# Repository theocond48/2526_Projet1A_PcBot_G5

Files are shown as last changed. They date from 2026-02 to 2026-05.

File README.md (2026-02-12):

# 2526_Projet1A_PcBot_G5

**Objectif :** Concevoir un robot communicant (Swarm) pour la cartographie d'environnement.
**Volume horaire :** 40 heures (10 séances x 4h).

- Travail en groupe réalisé par: Youssef Chemrakhi, Théodore Condette, Rayan Taoussi, Samy, Maroua Qidi.

# I - Phase 1 : Conception et Saisie de Schéma
- **Séance 1 : Initialisation & Spécifications**

- **Définition du Besoin**
  - Liste des fonctionnalités
  - Schéma architectural
- **Planification et Matériel**
  - Planning prévisionnel
  - Choix des composants

# 1 - Liste des fonctionnalités
Le robot doit être capable de:
- **Navigation et Évitement d'obstacles :** Détection d'objets en temps réel via les capteurs **VL53L0X (TOF)** pour ajuster la trajectoire.
- **Localisation Relative:** Suivi du déplacement et de l'orientation grâce à la centrale inertielle **LSM6DSOX** (Accéléromètre/Gyroscope).
- **Cartographie Collaborative :** Envoi des points de données de l'environnement vers les autres robots ou une station de base via le module **nRF24**.
- **Gestion de Swarm :** Capacité à recevoir des instructions ou à partager sa position pour éviter que deux robots ne couvrent la même zone.
- **Pilotage de Puissance :** Contrôle précis de la vitesse et de la direction des micro-moteurs **DFR1224** via le driver **DRV8411A**.
- **Autonomie Énergétique :** Recharge sécurisée de la batterie Li-ion et monitoring de la tension via le contrôleur **BQ25896**.

## 1.2 -Détails des composants 

## BMS bq25896

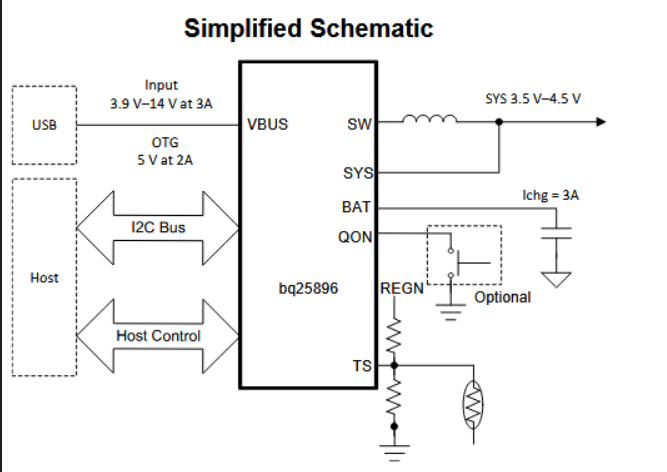
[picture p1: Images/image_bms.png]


- **C'est quoi ?** Le gestionnaire d'énergie intelligent.
    
- **Sa mission :**
    
    1. Il prend le 5V de l'USB pour charger la batterie LiPo en toute sécurité.
        
    2. Il protège la batterie (surcharge/décharge profonde).
        
    3. Il fournit l'énergie principale (SYS) au reste du robot.
        
- **Pourquoi c'est vital ?** Sans lui, ta batterie LiPo pourrait prendre feu ou mourir prématurément.

### Pin configuration BMS :

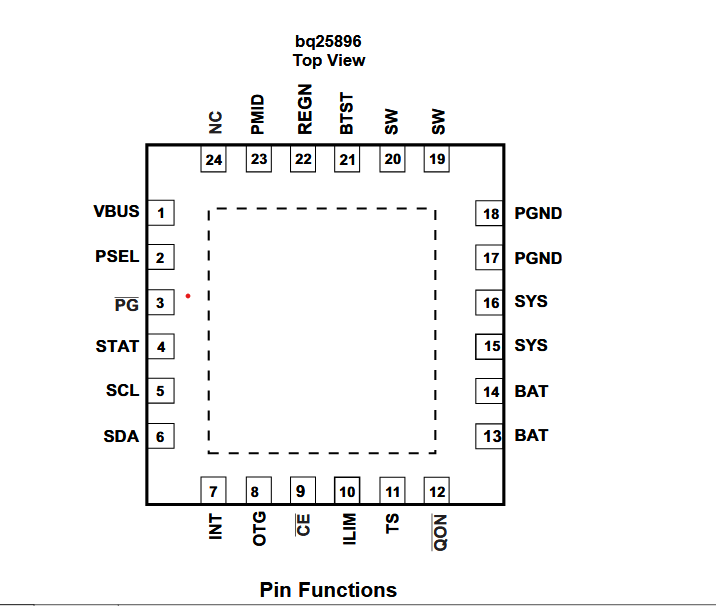
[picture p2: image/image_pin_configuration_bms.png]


**Netlist:**

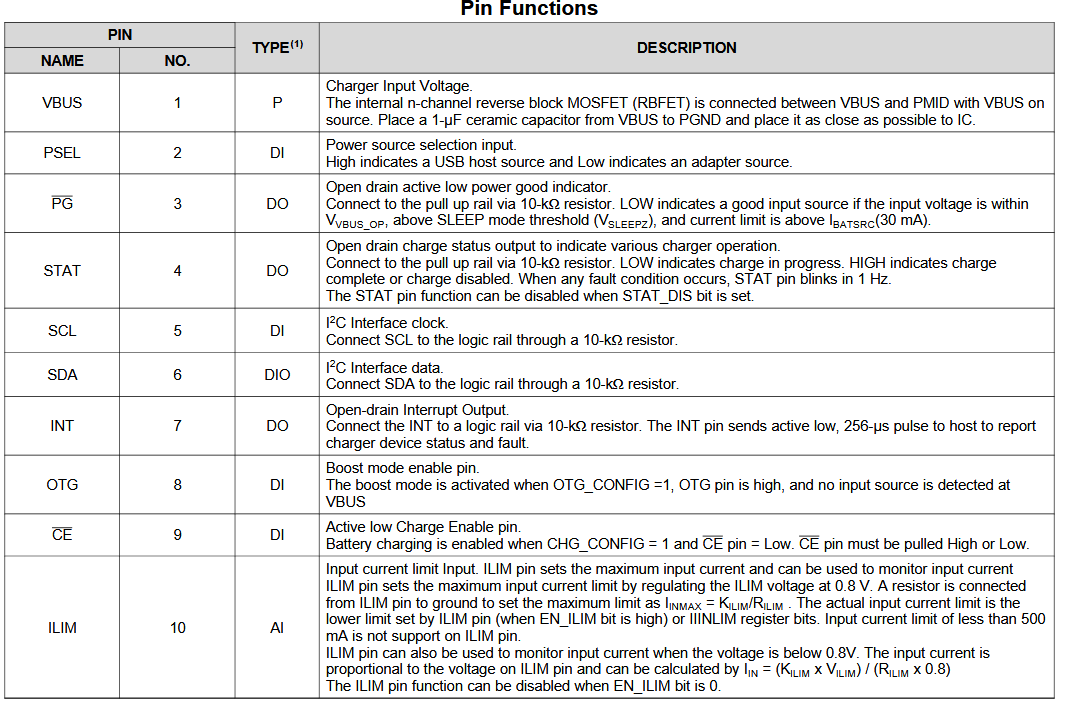
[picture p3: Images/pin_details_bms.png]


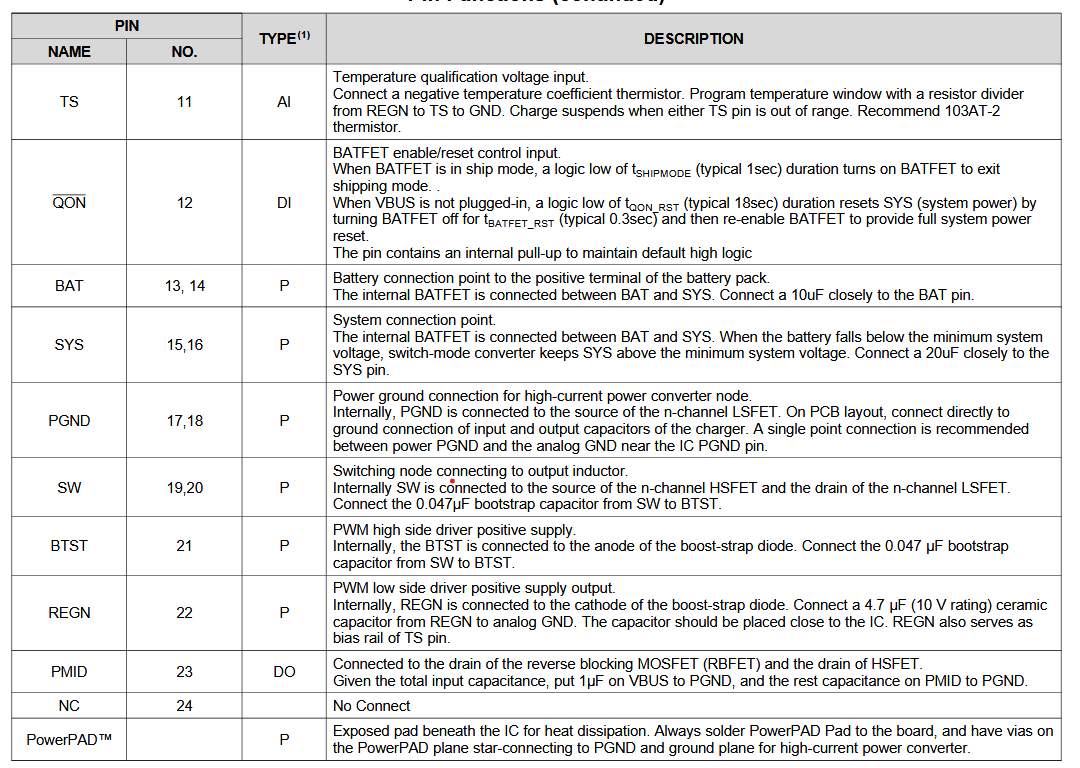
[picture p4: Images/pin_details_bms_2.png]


## Motor's Driver DRV8411A 

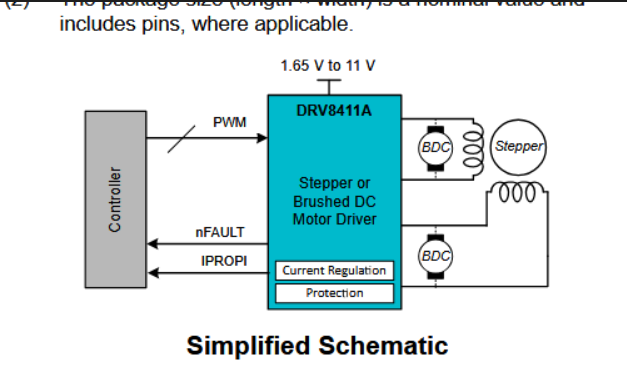
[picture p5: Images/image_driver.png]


- **C'est quoi ?** L'amplificateur de puissance.
    
- **Sa mission :** Le STM32 est trop faible pour faire tourner les moteurs directement. Le DRV8411A prend les petits ordres logiques (3.3V) et ouvre les vannes du "gros courant" venant de la batterie pour faire tourner les roues.
    
- **Pourquoi c'est vital ?** Il protège le STM32 des retours de courant inductif des moteurs.
### Pin configuration Driver

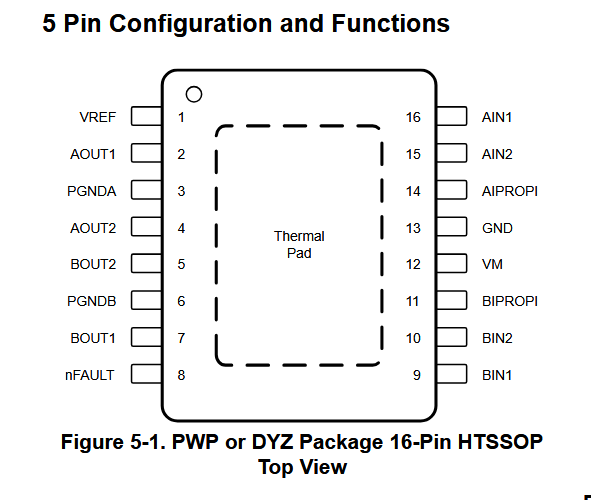
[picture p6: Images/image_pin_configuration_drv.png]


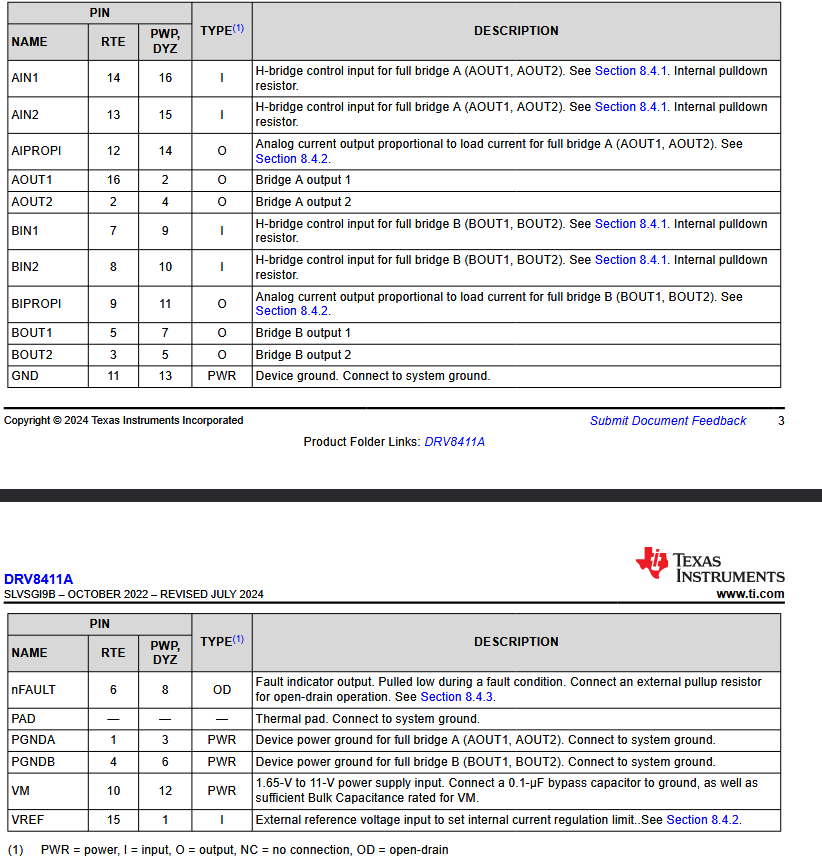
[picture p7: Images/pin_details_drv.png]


## imu adafruit (centrale inertielle)

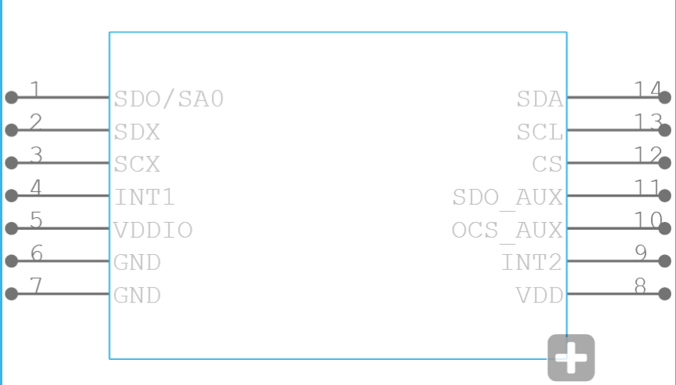
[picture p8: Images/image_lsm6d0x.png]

 LSM6DSOX (IMU - Accéléromètre/Gyroscope)

- **C'est quoi ?** Le capteur d'équilibre et de mouvement.
    
- **Sa mission :** Il sent si le robot accélère, tourne, ou s'il cogne un mur (choc). Il permet de faire avancer le robot bien droit (en corrigeant la trajectoire si une roue tourne plus vite que l'autre).
    
### Pin configuration imu

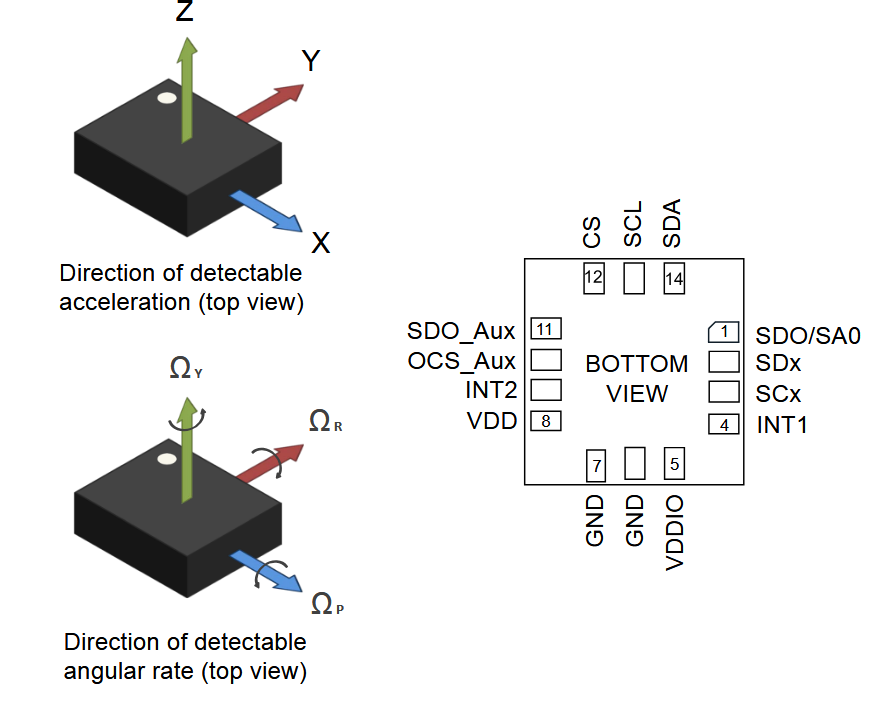
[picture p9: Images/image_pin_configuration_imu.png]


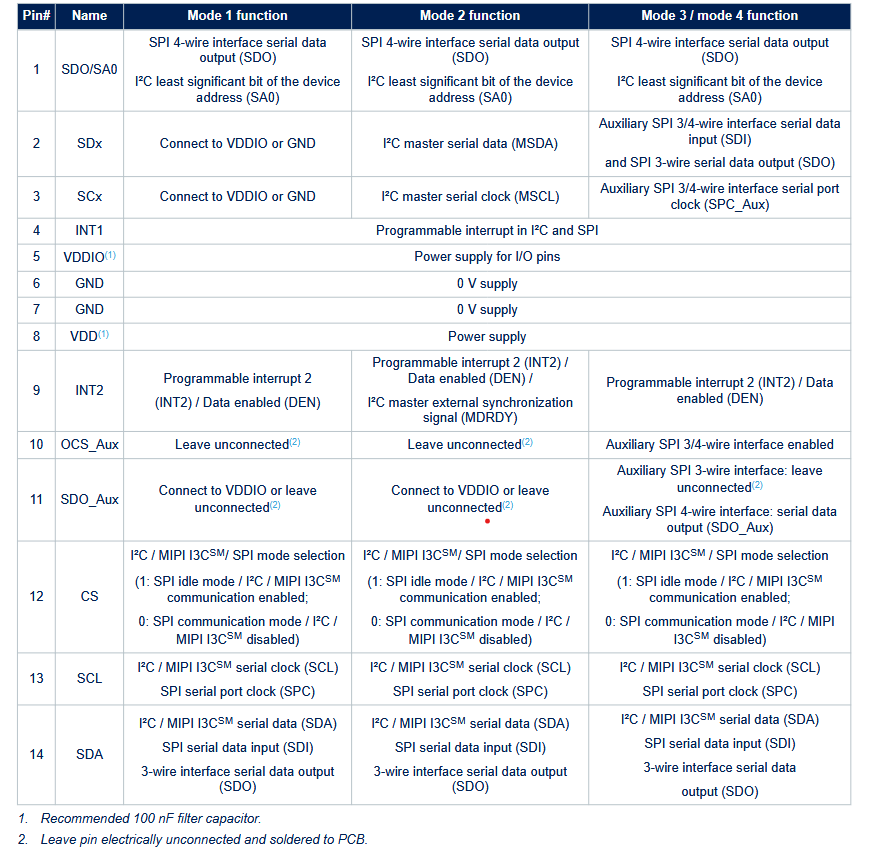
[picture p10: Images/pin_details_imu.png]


## Tof vl53lx
VL53L0X (ToF - Time of Flight)

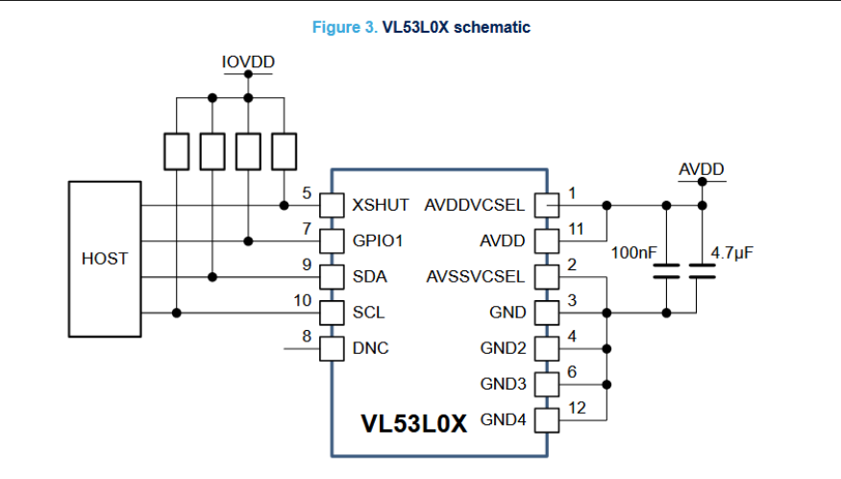
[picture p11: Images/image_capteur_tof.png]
image capteur


- **C'est quoi ?** Le télémètre laser.
    
- **Sa mission :** Il envoie un rayon de lumière invisible (infrarouge) et mesure le temps qu'il met à revenir. Cela lui donne la distance précise de l'obstacle devant lui (en millimètres).

### Pin configuration tof
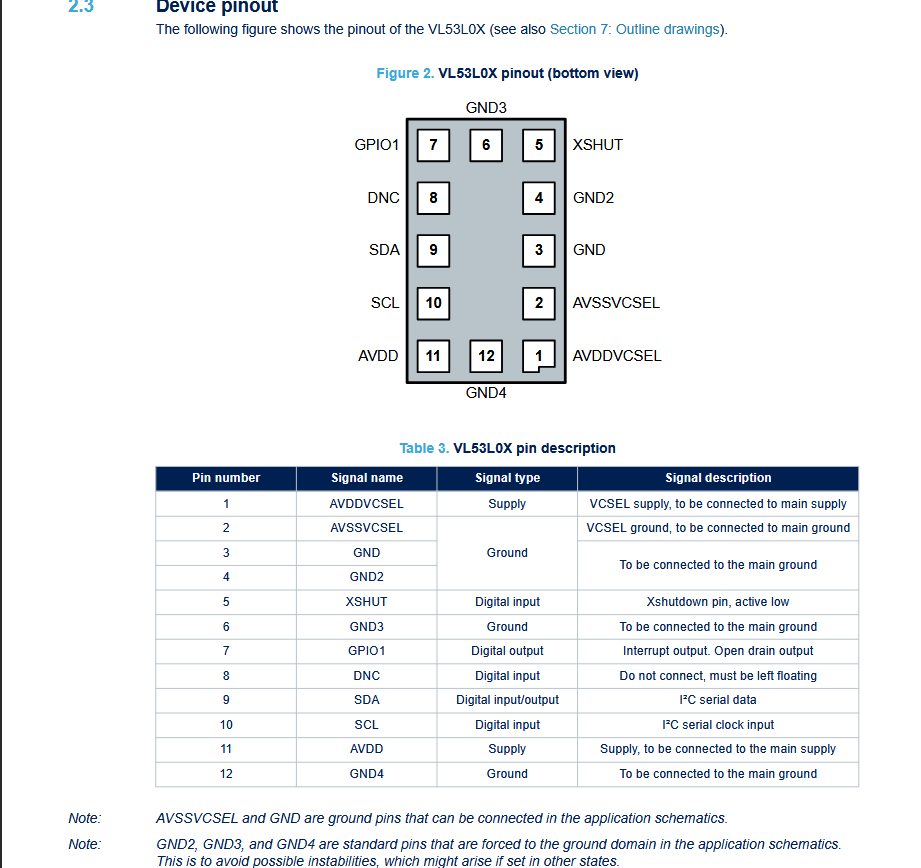
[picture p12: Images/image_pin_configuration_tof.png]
pin capteur

VL53L0X (ToF - Time of Flight)

- **C'est quoi ?** Le télémètre laser.
    
- **Sa mission :** Il envoie un rayon de lumière invisible (infrarouge) et mesure le temps qu'il met à revenir. Cela lui donne la distance précise de l'obstacle devant lui (en millimètres).

## motor DFR1224
(Moteurs N20 3V)

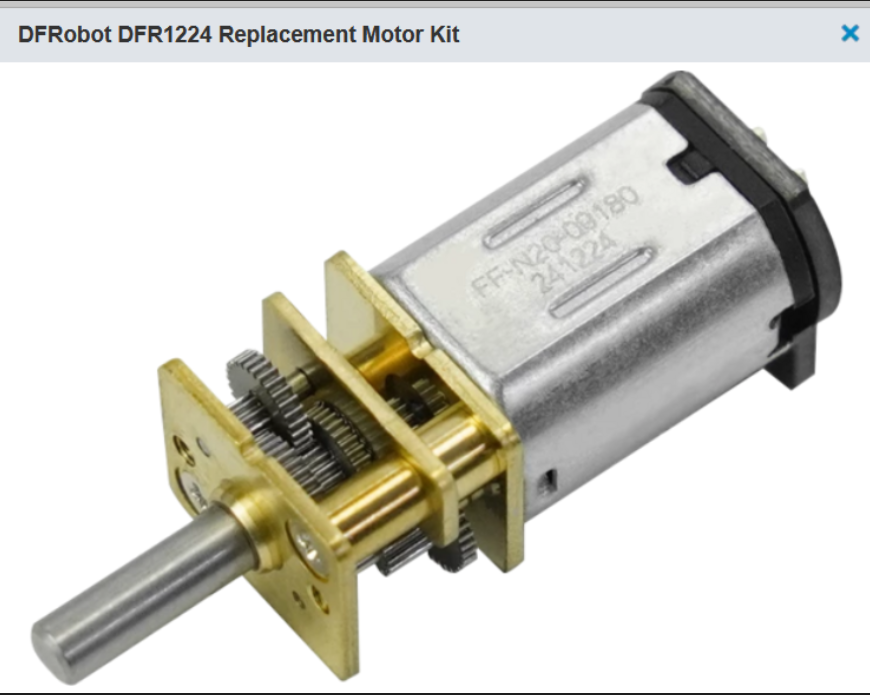
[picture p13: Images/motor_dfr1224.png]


- **C'est quoi ?** Les actionneurs.
    
- **Sa mission :** Convertir l'électricité en mouvement mécanique. Ils ont une boîte de vitesses (engrenages) intégrée pour avoir du couple (force) plutôt que de la vitesse pure.
    
- **Rappel critique :** Ce sont des moteurs **3V**. Ils doivent être alimentés avec précaution via le PWM du driver.

## module de communication nRF24l01
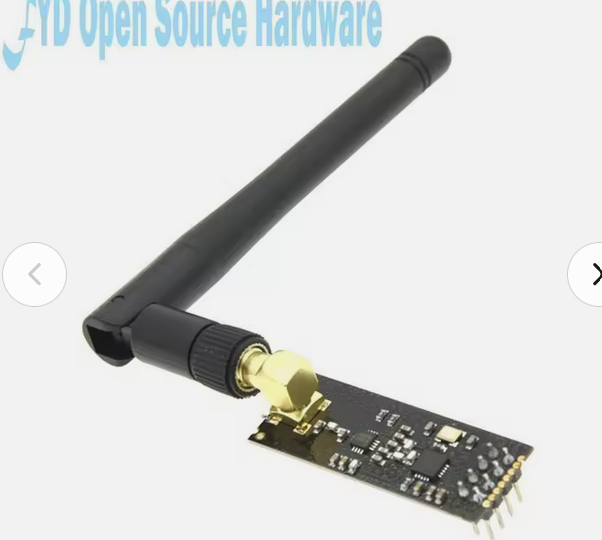
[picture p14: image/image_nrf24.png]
image nrf


### Pin configuration nrf
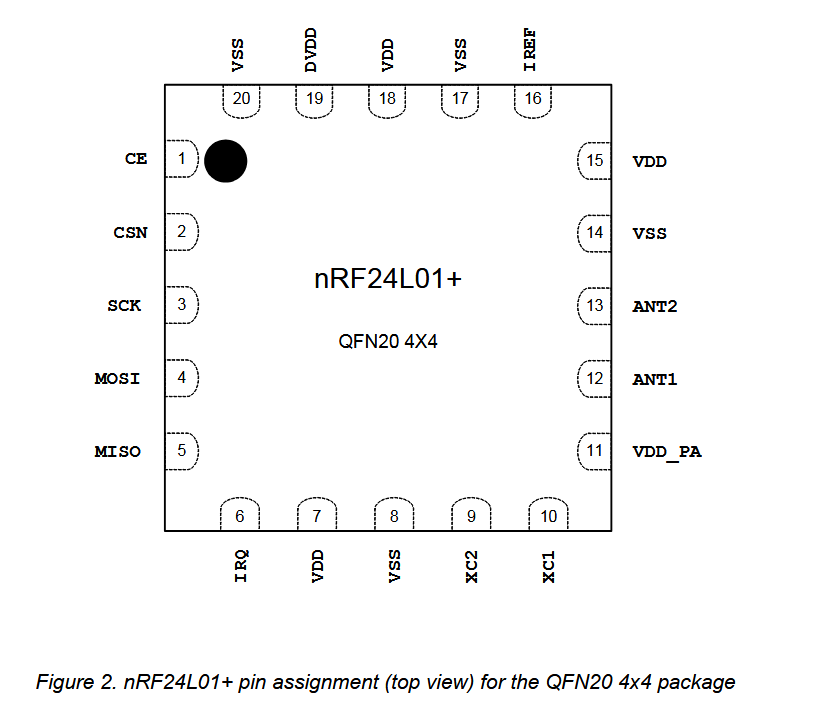
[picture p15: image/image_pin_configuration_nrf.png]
pin nrf


**Netlist**
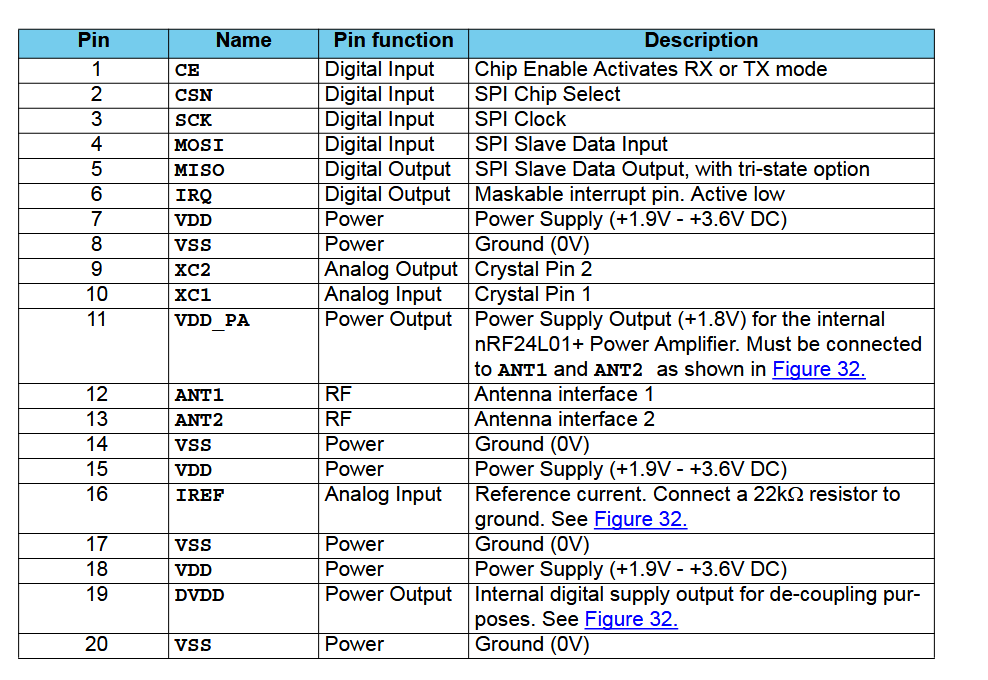
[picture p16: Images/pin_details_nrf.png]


# 2 - Schéma architectural

Le schéma ci-dessous illustre l'organisation du système. Le microcontrôleur (MCU) agit comme le cerveau central, coordonnant les capteurs (entrées), les actionneurs (sorties) et la communication.

```mermaid
graph TD
    %% Alimentation
    subgraph Power_System [Gestion Énergie]
        BAT[Batterie Li-ion] --- BMS[BMS: BQ25896]
        BMS -- I2C --> MCU[STM32L476]
    end

    %% Capteurs
    subgraph Perception [Capteurs / Entrées]
        TOF[Télémètres: VL53L0X] -- I2C --> MCU
        IMU[Centrale Inertielle: LSM6DSOX] -- I2C --> MCU
    end

    %% Communication
    subgraph Comms [Lien Essaim]
        nRF[Radio: nRF24L01] <-->|SPI| MCU
    end

    %% Actionneurs
    subgraph Motion [Actionneurs / Sorties]
        MCU -- PWM --> DRV[Driver: DRV8411]
        DRV --> M1[Moteur Gauche: DFR1224]
        DRV --> M2[Moteur Droit: DFR1224]
    end

    %% Styles
    style MCU fill:#f9f,stroke:#333,stroke-width:2px
    style BMS fill:#dfd
    style nRF fill:#ddf
```

Afin d'assurer les connexions données, on se reposera sur la Datasheet qui nous donne l'ensembles des ports de la STM32L476 qui sont configurés en I2C et SPI:

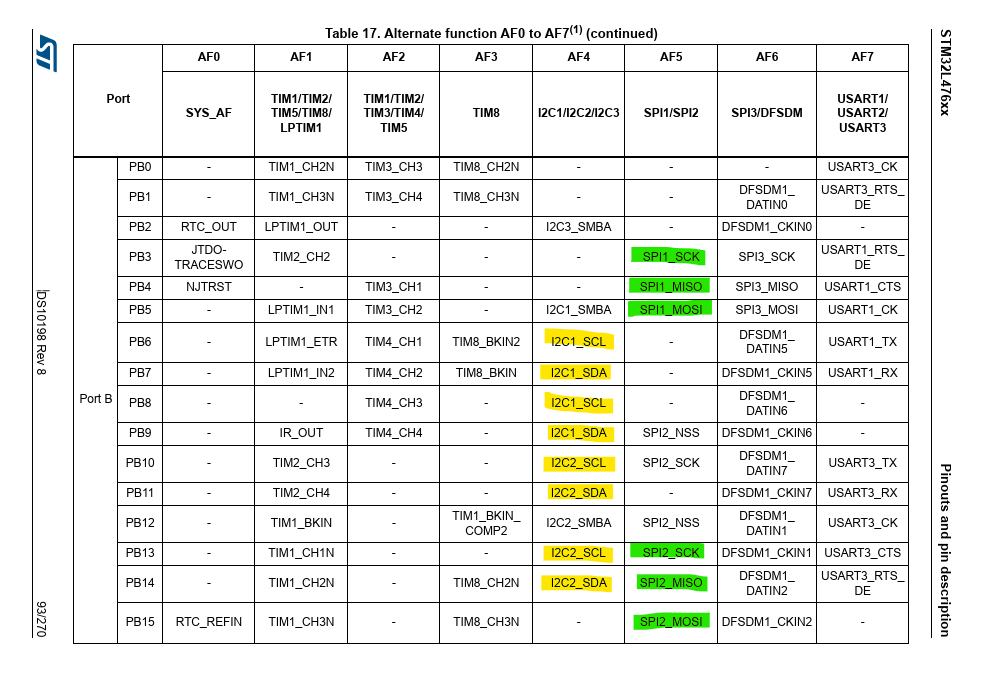
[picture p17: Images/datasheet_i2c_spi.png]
Tableau des fonctions alternées STM32


# 3 - Planning Prévisionnel - Projet PCBot

## Phase 1 : Conception et Saisie de Schéma
- **Séance 1 : Initialisation & Spécifications**
  - Formation du groupe.
  - Création du dépôt Git et ajout du professeur (laurent.fiack@ensea.fr).
  - Étude des composants : Capteurs TOF, Accéléromètre, nRF24, Batterie/Chargeur.
- **Séance 2 : Saisie de schéma**
  - Début de la saisie sur KiCad des blocs d'alimentation et du microcontrôleur.
- **Séance 3 : Revue de schéma & Finalisation**
  - Revue critique des connexions.
  - Finalisation du schéma complet avant les vacances de février.

## Phase 2 : Routage et Fabrication
- **Séance 4 : Placement et Routage**
  - Placement des composants sur le PCB.
  - Routage des pistes.
- **Séance 5 : Revue de routage & Commande**
  - **Critique :** Validation finale du routage.
  - Génération et envoi des fichiers de fabrication (Gerber).

## Phase 3 : Firmware et Intégration
- **Séance 6 : Tests préliminaires & Firmware**
  - Tests sur cartes de développement.
  - Développement des drivers pour les capteurs TOF et le module nRF24.
- **Séance 7 : Développement Firmware**
  - Implémentation des algorithmes de cartographie et de communication Swarm.
- **Séance 8 : Firmware & Soudure**
  - Réception possible des PCB.
  - Assemblage (soudure) et tests de continuité.
- **Séance 9 : Intégration Finale & Débogage**
  - Tests en conditions réelles du robot.
  - Correction des derniers bugs du firmware.

## Phase 4 : Clôture
- **Séance 10 : Finitions & Démo**
  - 2h : Préparation finale et finitions.
  - 2h : Présentation et démonstration du projet.

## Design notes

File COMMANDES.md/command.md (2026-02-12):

## Rappels Git

### Clé SSH

Créer une clé :

```bash
ssh-keygen
```

Afficher la clé ssh

```bash
cat /c/Users/<USER>/.ssh/id_ed25519.pub
```

### Cloner un projet

Clonage = récupérer le projet. A faire une fois par projet. 

```bash
cd <chemin/vers/le/bon/dossier>
git clone git@github.com:theocond48/2526_Projet1A_PcBot_G5.git
```

### Voir l'état du projet

```bash
git status
```

### Pousser des modifications 

On dit "committer" ou "faire un commit".
A faire à chaque fois qu'on a une nouvelle version fonctionnelle.

```bash
git add .   # Ajoute tous les fichiers
git commit -m "Message"
git push    # Pousse les modifications
```

### Récupérer les dernières mises à jour

A faire à chaque fois qu'on commence à travailler.

```bash
git pull
```

### Créer un fichier sur git ou un dossier

```bash
# Sur Mac ou Linux (ou terminal Git Bash) Pour un fichier :
touch nom.md

# Pour un dossier
mkdir nom
```

### Changer de branche

```bash
git checkout nom-de-la-branche
```

### Créer une branche

```bash
# -b, c'est pour créer la branche puis s'y déplacer directement.
git checkout -b nom-de-la-nouvelle-branche
```

### Comment faire un merge sur Github

C'est pour travailler proprement en équipe, éviter d'écraser le travail des autres et garder un historique clair.

```bash
# On se place sur la branche qui doit recevoir les changements :
git checkout base-branch

# On met à jour cette branche :
git pull

# On merge la branche de travail :
git merge compare-branch

# Si tout va bien, on pushe :
git push
```

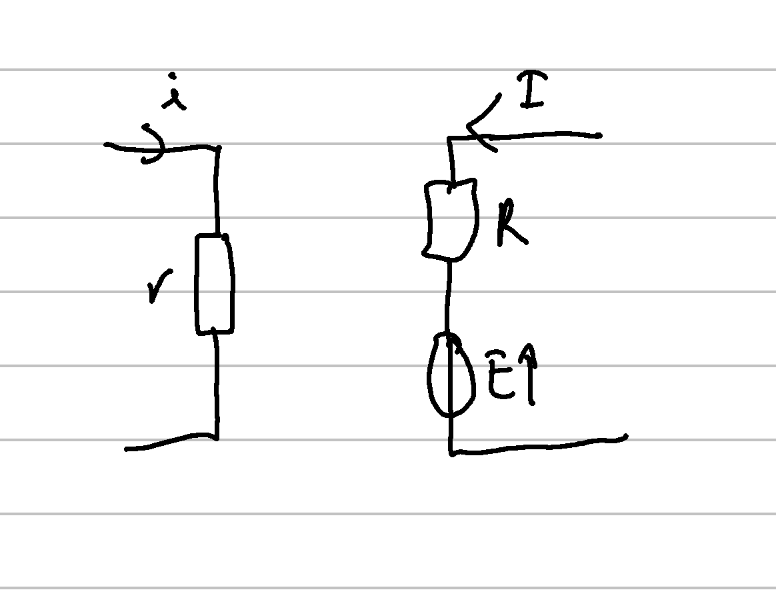
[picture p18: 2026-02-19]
image/Capture d’écran 2026-02-18 081915.png

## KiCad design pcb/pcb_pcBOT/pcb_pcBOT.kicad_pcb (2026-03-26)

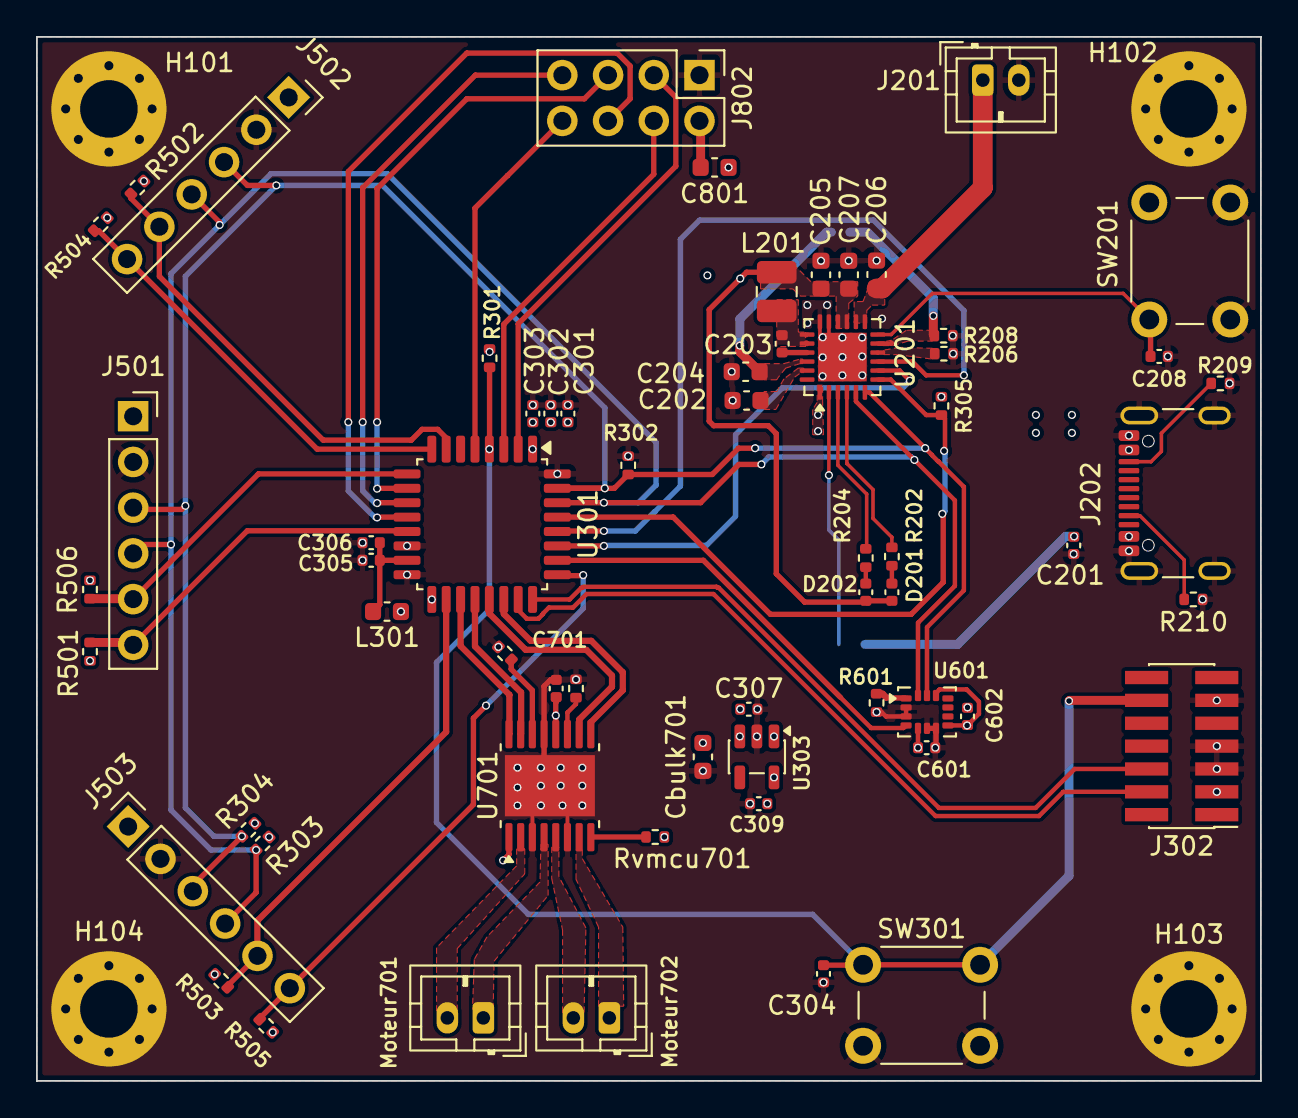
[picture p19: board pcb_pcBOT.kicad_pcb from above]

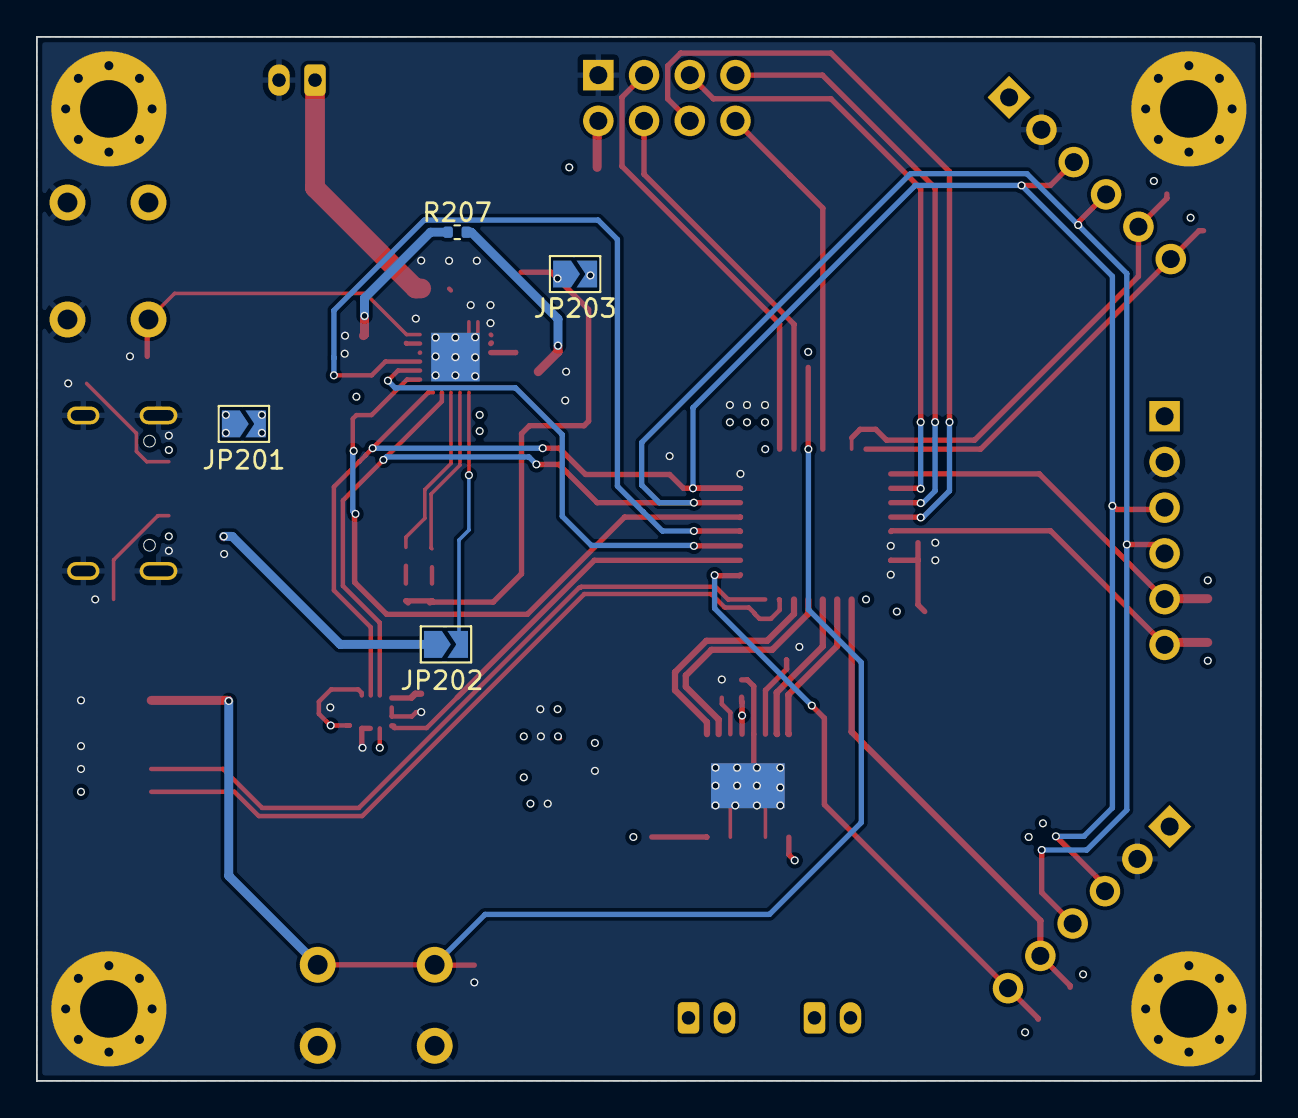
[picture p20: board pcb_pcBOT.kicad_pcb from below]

Board: 4 copper layers, 68.0 x 58.0 mm, 70 parts (4 on the bottom side), 56 nets.

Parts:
C201, C305, C307, C309: 1u; C_0402_1005Metric
C202, C205, C206, C207, C801: 10u; C_0603_1608Metric
C203: 47n; C_0402_1005Metric
C204: 4.7u; C_0603_1608Metric
C208, C301, C302, C303, C304, C306, C601, C602, C701: 100n; C_0402_1005Metric
Cbulk701: 10u; C_0603_1608Metric
D201, D202: LED; C_0402_1005Metric
H101, H102, H103, H104: MountingHole_Pad; MountingHole_3.2mm_M3_Pad_Via
J201: Lipo; JST_PH_B2B-PH-K_1x02_P2.00mm_Vertical
J202: USB_C_Receptacle_USB2.0_16P; USB_C_Receptacle_GCT_USB4105-xx-A_16P_TopMnt_Horizontal
J302: Conn_ST_STDC14; PinHeader_2x07_P1.27mm_Vertical_SMD
J501: TOF1; PinSocket_1x06_P2.54mm_Vertical
J502: TOF2; PinSocket_1x06_P2.54mm_Vertical
J503: TOF3; PinSocket_1x06_P2.54mm_Vertical
J802: nrF24l01_rf; PinHeader_2x04_P2.54mm_Vertical
JP201, JP202, JP203: SolderJumper_2_Open; SolderJumper-2_P1.3mm_Open_TrianglePad1.0x1.5mm
L201: 1u; L_1008_2520Metric
L301: 10n; C_0603_1608Metric
Moteur701, Moteur702: Conn_01x02; JST_PH_B2B-PH-K_1x02_P2.00mm_Vertical
R202, R204, R303, R304, R305: 2.2k; R_0402_1005Metric
R206: 260; R_0402_1005Metric
R207, R208, R301, R302, R501, R502, R503, R504, R505, R506, R601: 10k; R_0402_1005Metric
R209, R210: 5k1; R_0402_1005Metric
R-B701: 16k5; R_0402_1005Metric
R-IPROPI_A701: 16k5; R_0402_1005Metric
Rvmcu701: 10k; R_0402_1005Metric
SW201: ~{QON}_BUTTON; SW_PUSH_6mm
SW301: Reset_Button; SW_PUSH_6mm
U201: BQ25896RTW; Texas_RTW_WQFN-24-1EP_4x4mm_P0.5mm_EP2.7x2.7mm_ThermalVias
U301: STM32G431KBT6; LQFP-32_7x7mm_P0.8mm
U303: BU33??; TSOT-23-5
U601: LSM6DSM; LGA-14_3x2.5mm_P0.5mm_LayoutBorder3x4y
U701: DRV8411A; HTSSOP-16-1EP_4.4x5mm_P0.65mm_EP3.4x5mm_Mask2.46x2.31mm_The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

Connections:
+5V: C307.1, C701.2, Cbulk701.1, JP203.2 (B), U303.1 (VIN), U303.3 (EN), U701.12 (VM)
/I2C_BUS.I2C_SCL: J501.3, J502.3, J503.3, R302.1, R304.2, U201.6 (SDA), U301.31 (PB8), U601.13 (SCL)
/I2C_BUS.I2C_SDA: J501.4, J502.4, J503.4, R303.2, U201.5 (SCL), U301.30 (PB7), U601.14 (SDA)
/SPI_BUS.MISO_NRF: J802.7, U301.11 (PA6)
/SPI_BUS.MOSI_NRF: J802.6, U301.12 (PA7)
/SPI_BUS.SCK_NRF: J802.5, U301.10 (PA5)
/bms/BAT: C206.1, J201.1, U201.13 (BAT), U201.14 (BAT)
/bms/BTST: C203.2, U201.21 (BTST)
/bms/ILIM: R206.2, U201.10 (ILIM)
/bms/INT_BMS: R305.2, U201.7 (INT), U301.29 (PB6)
/bms/OTG_HOST: U201.8 (OTG), U301.27 (PB4)
/bms/PMID: C202.1, U201.23 (PMID)
/bms/REGN: C204.2, R207.1, U201.22 (REGN)
/bms/STAT: R202.2, U201.4 (STAT)
/bms/SW: C203.1, L201.1, U201.19 (SW), U201.20 (SW)
/bms/SYS: C205.1, C207.1, D201.2 (A), D202.2 (A), JP203.1 (A), L201.2, U201.15 (SYS), U201.16 (SYS)
/bms/TS: R207.2, R208.1, U201.11 (TS)
/bms/VBUS_BQ25: JP201.2 (B), U201.1 (VBUS)
/bms/~CE_HOST: U201.9 (~CE), U301.28 (PB5)
/bms/~PG: R204.2, U201.3 (~PG)
/bms/~QON: C208.1, SW201.1, U201.12 (~QON)
/capteur tof/TOF_INT1: J501.5, R506.2, U301.9 (PA4)
/capteur tof/TOF_INT2: J502.5, R502.2, U301.7 (PA2)
/capteur tof/TOF_INT3: J503.5, R503.2, U301.18 (PA8)
/capteur tof/XSHUT1: J501.6, R501.2, U301.13 (PB0)
/capteur tof/XSHUT2: J502.6, R504.2, U301.8 (PA3)
/capteur tof/XSHUT3: J503.6, R505.2, U301.25 (PA15)
/centrale imu/IMU_INT1: U301.26 (PB3), U601.4 (INT1)
/driver_motor/MOT_AIN1: U301.19 (PA9), U701.16 (AIN1)
/driver_motor/MOT_AIN2: U301.20 (PA10), U701.15 (AIN2)
/driver_motor/MOT_BIN1: U301.22 (PA12), U701.9 (BIN1)
/driver_motor/MOT_BIN2: U301.21 (PA11), U701.10 (BIN2)
/nrf24l01/CE_NRF: J802.3, U301.2 (PF0)
/nrf24l01/CSN_NRF: J802.4, U301.3 (PF1)
/nrf24l01/IRQ_NRF: J802.8, U301.5 (PA0)
/stm32/NRST: C304.1, J302.12 (~RST), R301.2, SW301.1, U301.4 (PG10)
/stm32/T_SWCLK: J302.6 (JCLK/SWCLK), U301.24 (PA14)
/stm32/T_SWDIO: J302.4 (JTMS/SWDIO), U301.23 (PA13)
GND: C201.2, C202.2, C204.1, C205.2, C206.2, C207.2, C208.2, C301.2, C302.2, C303.2, C304.2, C305.2, C306.2, C307.2, C309.2, C601.2, C602.2, C701.1, Cbulk701.2, H101.1, H102.1, H103.1, H104.1, J201.2, J202.A1 (GND), J202.A12 (GND), J202.B1 (GND), J202.B12 (GND), J202.S1 (SHIELD), J302.5 (GND), J302.7 (GND), J302.11 (GNDDetect), J501.2, J502.2, J503.2, J802.1, R206.1, R208.2, R209.2, R210.2, R302.2, R601.1, R-B701.2, R-IPROPI_A701.2, SW201.2, SW301.2, U201.17 (PGND), U201.18 (PGND), U201.25 (PGND), U301.14 (VSSA), U301.16 (VSS), U301.32 (VSS), U303.2 (GND), U601.2 (SDX), U601.3 (SCX), U601.6 (GND), U601.7 (GND), U701.3 (PGNDA), U701.6 (PGNDB), U701.13 (GND), U701.17 (PPAD)
I: Rvmcu701.2, U701.8 (nFAULT)
unnamed: D201.1 (K), R202.1
unnamed: D202.1 (K), R204.1
unnamed: J202.A5 (CC1), R210.1
unnamed: J202.B5 (CC2), R209.1
unnamed: C801.1, J802.2
unnamed: JP202.2 (B), U201.2 (PSEL)
unnamed: Moteur701.1, U701.4 (AOUT2)
unnamed: Moteur701.2, U701.2 (AOUT1)
unnamed: Moteur702.1, U701.7 (BOUT1)
unnamed: Moteur702.2, U701.5 (BOUT2)
unnamed: R601.2, U601.1 (SDO/SA0)
unnamed: R-IPROPI_A701.1, U701.14 (AIPROPI)
unnamed: R-B701.1, U701.11 (BIPROPI)
VBUS: C201.1, J202.A4 (VBUS), J202.A9 (VBUS), J202.B4 (VBUS), J202.B9 (VBUS), JP201.1 (A), JP202.1 (A)
VDD: C301.1, C302.1, C303.1, C309.1, C601.1, C602.1, C801.2, J302.3 (VCC), J501.1, J502.1, J503.1, L301.1, R301.1, R303.1, R304.1, R305.1, R501.1, R502.1, R503.1, R504.1, R505.1, R506.1, Rvmcu701.1, U301.1 (VDD), U301.17 (VDD), U303.5 (VOUT), U601.5 (VDDIO), U601.8 (VDD), U601.12 (CS), U701.1 (VREF)
VDDA: C305.1, C306.1, L301.2, U301.15 (VDDA)

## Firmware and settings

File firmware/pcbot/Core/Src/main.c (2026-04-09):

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
/* Includes ------------------------------------------------------------------*/
#include "main.h"
#include "motors.h"
#include "robot.h"
I2C_HandleTypeDef hi2c1;

TIM_HandleTypeDef htim1;
TIM_HandleTypeDef htim2;

void SystemClock_Config(void);
static void MX_GPIO_Init(void);
static void MX_I2C1_Init(void);
static void MX_TIM1_Init(void);
static void MX_TIM2_Init(void);
/**
  * @brief  The application entry point.
  * @retval int
  */
int main(void)
{

  /* MCU Configuration--------------------------------------------------------*/

  /* Reset of all peripherals, Initializes the Flash interface and the Systick. */
  HAL_Init();

  /* Configure the system clock */
  SystemClock_Config();

  /* Initialize all configured peripherals */
  MX_GPIO_Init();
  MX_I2C1_Init();
  MX_TIM1_Init();
  MX_TIM2_Init();
  Motors_Init();
  /* USER CODE BEGIN 2 */
  RobotMode_t currentMode = MODE_NAVIGATION;
  // IMU_Calibration();


if (!initVL53L0X(true, &hi2c1)) {
    // Erreur d'initialisation (problème de câblage ou d'adresse I2C)
    return 0
}

  /* USER CODE END 2 */

  /* Infinite loop */
  /* USER CODE BEGIN WHILE */
  while (1)
  {
    Robot_logic(&currentMode);
  
    //uint32_t tickstart = HAL_GetTick();
    //IMU_getacceleration + calculer position
    //Transmettre les données sur nRF24
    Tof_Distance();
    float vL=0.0f , vR= 0.0f;
    Compute_asserv(dist_front, &vL, &vR);
    apply_motor_speeds(vL, vR);

    HAL_Delay (20);
    //while delay
    /* USER CODE END WHILE */

    /* USER CODE BEGIN 3 */
  }
  /* USER CODE END 3 */
}

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


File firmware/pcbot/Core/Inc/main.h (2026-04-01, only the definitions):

#define CE_NRF_Pin GPIO_PIN_0
#define CE_NRF_GPIO_Port GPIOF
#define CSN_NRF_Pin GPIO_PIN_1
#define CSN_NRF_GPIO_Port GPIOF
#define IRQ_NRF_Pin GPIO_PIN_0
#define IRQ_NRF_GPIO_Port GPIOA
#define TOF_INT2_Pin GPIO_PIN_2
#define TOF_INT2_GPIO_Port GPIOA
#define XSHUT2_Pin GPIO_PIN_3
#define XSHUT2_GPIO_Port GPIOA
#define TOF_INT1_Pin GPIO_PIN_4
#define TOF_INT1_GPIO_Port GPIOA
#define XSHUT1_Pin GPIO_PIN_0
#define XSHUT1_GPIO_Port GPIOB
#define TOF_INT3_Pin GPIO_PIN_8
#define TOF_INT3_GPIO_Port GPIOA
#define MOT_AIN1_Pin GPIO_PIN_9
#define MOT_AIN1_GPIO_Port GPIOA
#define MOT_AIN2_Pin GPIO_PIN_10
#define MOT_AIN2_GPIO_Port GPIOA
#define MOT_BIN2_Pin GPIO_PIN_11
#define MOT_BIN2_GPIO_Port GPIOA
#define MOT_BIN1_Pin GPIO_PIN_12
#define MOT_BIN1_GPIO_Port GPIOA
#define XSHUT3_Pin GPIO_PIN_15
#define XSHUT3_GPIO_Port GPIOA
#define IMU_INT1_Pin GPIO_PIN_3
#define IMU_INT1_GPIO_Port GPIOB
#define OTG_BMS_Pin GPIO_PIN_4
#define OTG_BMS_GPIO_Port GPIOB
#define CE_BMS_Pin GPIO_PIN_5
#define CE_BMS_GPIO_Port GPIOB
#define INT_BMS_Pin GPIO_PIN_6
#define INT_BMS_GPIO_Port GPIOB

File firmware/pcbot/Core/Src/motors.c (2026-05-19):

#include "motors.h"
#include "main.h"
#include "IMU.h"
#include "AsservAndOther.h"

#define CORRECTION
#define PIVOT

//1.Écriture du registre CCR 
//Moteur A- AIN1 : TIM2 channel 3
static inline void _set_AIN1(uint32_t duty)
{
    __HAL_TIM_SET_COMPARE( &htim2, TIM_CHANNEL_3, duty);
}

//Moteur A- AIN2 : TIM1 channel 3
static inline void _set_AIN2 (uint32_t duty)
{
    __HAL_TIM_SET_COMPARE( &htim1, TIM_CHANNEL_3, duty);
}

//Moteur B- BIN1 : TIM1 channel 2
static inline void _set_BIN1(uint32_t duty)
{
    __HAL_TIM_SET_COMPARE( &htim1, TIM_CHANNEL_2, duty);
}

//Moteur B- BIN2 : TIM1 channel 1 
static inline void _set_BIN2( uint32_t duty)
{
    __HAL_TIM_SET_COMPARE( &htim1, TIM_CHANNEL_1, duty);
}

//2. Motors_Init
void Motors_Init(void)
{
    //2.1. Démarrer TIM2 CH3 → AIN1
    HAL_TIM_PWM_Start( &htim2, TIM_CHANNEL_3);

    //2.2. Démarrer TIM1 CH3 → AIN2
    HAL_TIM_PWM_Start( &htim1, TIM_CHANNEL_3);

    //2.3. Démarrer TIM1 CH2N → BIN1 
    HAL_TIMEx_PWMN_Start (&htim1, TIM_CHANNEL_2);

    //2.4. Démarrer TIM1 CH1N → BIN2
    HAL_TIMEx_PWMN_Start (&htim1, TIM_CHANNEL_1);

    //2.5. Tout à 0 au démarrage
    _set_AIN1(0); _set_AIN2(0);
    _set_BIN1(0); _set_BIN2(0);
}

//3. Motor_A_Set (roue gauche)

void Motor_A_Set(int32_t speed)
{
    //Saturation
    if (speed> (int32_t)PWM_MAX) speed = (int32_t)PWM_MAX;
    if (speed < -(int32_t)PWM_MAX) speed = -(int32_t)PWM_MAX;

    //Zone morte : en dessous de seuil les moteurs ne tournent pas 

    if ( speed > 0 && speed < (int32_t)PWM_DEADBAND) speed  0;
    if ( speed > 0 && speed > -(int32_t)PWM_DEADBAND) speed  0;

    if (speed>0)
    {
        //Avant
        _set_AIN1((uint32_t)speed);
        _set_AIN2(0u);
    }
    else if (speed<0)
    {
        //Arrière 
        _set_AIN1(0u);
        _set_AIN2 ((uint32_t)(-speed));    
    }
    else 
    {
        //Coast
        _set_AIN1(0u);
        _set_AIN2(0u);
    }
}

// 4. Motot_B_Set (roue droite)

void Motor_B_Set(int32_t speed)
{
    //Saturation
    if (speed> (int32_t)PWM_MAX) speed= (int32_t)PWM_MAX;
    if (speed < -(int32_t)PWM_MAX) speed= -(int32_t)PWM_MAX;

    //Zone morte 
    if( speed>0 && speed< (int32_t)PWM_DEADBAND) speed 0;
    if ( speed >0 && speed > -(int32_t)PWM_DEADBAND) speed 0;

    if (speed>0)
    {
        //Avant
        _set_BIN1 ((uint32_t)speed);
        _set_BIN2 (0u);
    }
    else if ( speed<0)
    {
        //Arrière
        _set_BIN1(0u);
        _set_BIN2((uint32_t)(-speed));
    }
    else{
        //Coast
        _set_BIN1(0u);
        _set_BIN2(0u);
    }
}

void set_motors(int32_t speedA, int32_t speedB)
{
    Motor_A_Set ( speedA);
    Motor_B_Set (speedB);
}

void apply_motor_speeds(float vL, float vR)
{
    //Saturation flottante
    if( vL> 1.0f) vL= 1.0f;
    if (vL< -1.0f) vL=-1.0f;
    if ( vR> 1.0f) vR= 1.0f;
    if ( vR< -1.0f) vR=-1.0f;

    //Conversion en ticks MPWM
    int32_t pwmL = (int32_t) (vL * (float)PWM_MAX) ;
    int32_t pwmR = (int32_t) (vR* (float)PWM_MAX);

    Motor_A_Set(pwmL);
    Motor_B_Set (pwmR);
}
void moteurs_legere_correction_droite(void){
    apply_motor_speeds(vRobot+ CORRECTION,vRobot- CORRECTION);
}
void moteurs_legere_correction_gauche(void){
    apply_motor_speeds(vRobot-CORRECTION,vRobot +CORRECTION );
}

void moteurs_pivoter_droite(void){
    apply_motor_speeds(PIVOT, -PIVOT);
}
void moteurs_pivoter_gauche(void){
    apply_motor_speeds(-PIVOT, PIVOT);
}

void moteurs_stop(void) {
    set_motors(0, 0);
} 

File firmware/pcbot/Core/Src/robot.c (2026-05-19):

/*
 * robot.c
 *
 *  Created on: Mar 26, 2026
 */

#include "robot.h"

#include "main.h"
#include "Tof.h"
#include "motors.h"

float pos_x = 0, pos_y = 0;
float vit_x = 0, vit_y = 0;
float offset_x = 0, offset_y = 0;
float dt = 0.02;

uint16_t dist_front, dist_left, dist_right;
void Robot_logic(RobotMode_t *currentMode) {
    // 1. Lecture de la distance (ToF sur I2C2)
    Tof_Read(&dist_front, &dist_left, &dist_right);

    // Gestion des états
    switch(*currentMode) {


        case MODE_NAVIGATION:
        	if (dist_front < 150 && dist_front > 0) {
        		*currentMode = MODE_EVITEMENT;
        	}
       // Si un mur s'approche trop par la gauche, on s'écarte à droite sans s'arrêter
        	else if (dist_left < 80) {
				moteurs_legere_correction_droite();  
        		}
        	else if (dist_right < 80) {
				 moteurs_legere_correction_gauche();
				}
        	break;


        case MODE_EVITEMENT:
        	// Si on est bloqué devant, on regarde quel côté est le plus libre
        	if (dist_left > dist_right) {
				 moteurs_pivoter_gauche();
        		printf("Dodge -> Gauche \r\n");
        	}
        	else {
				 moteurs_pivoter_droite();
        		printf("Dodge -> Droite \r\n");
        	}

        // On sort de l'évitement quand le champ devant est libre
        	if (dist_front > 300 || dist_front == 0) {
        		*currentMode = MODE_NAVIGATION;
        	}
        	break;

        case MODE_STOP:
		moteurs_stop();
            break;
    }
}

void Robot_Position() {
	uint32_t tickstart = HAL_GetTick();
	int16_t brut_x, brut_y;
	//read_accelero(&brut_x, &brut_y);
	//read_tof();

	//Calcul physique (Conversion en m/s^2)
	float ax = ((float)brut_x - offset_x) * 0.00061f;
	float ay = ((float)brut_y - offset_y) * 0.00061f;

	//Seuil anti-bruit
	if(ax < 0.05 && ax > -0.05) ax = 0;
	if(ay < 0.05 && ay > -0.05) ay = 0;

	//Intégration
	vit_x += ax * dt;
	vit_y += ay * dt;
	pos_x += vit_x * dt;
	pos_y += vit_y * dt;

	while ((HAL_GetTick() - tickstart) < 20)
	{
	}
}

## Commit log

2026-02-05 j'ai enlevé les modifications
2026-02-05 fiche technique du BMS
2026-02-05 plus de doc
2026-02-05 j'ai ajoute les datasheets
2026-02-08 J'ai modifié le fichier READme et j'ai ajouté l'ensemble des documentations sur le fichier Documentation
2026-02-08 Modifs de READme
2026-02-09 J'ai ajouté la Datasheet I2C,SPI
2026-02-09 Modifs de nouveau
2026-02-09 J'ai enlevé les rappels git
2026-02-09 J'ai ajouté des commandes utiles de git
2026-02-09 je fix les problèmes d'images
2026-02-12 j'ai ajoute la commande pour creer une branche
2026-02-12 creation du fichier pcb et des feuilles kicad
    [battery.kicad_sch, bms.kicad_sch, dfr.kicad_sch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]
2026-02-12 ajout de la librairie composant
    [bms.kicad_sch, drv.kicad_sch, imu.kicad_sch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]
2026-02-12 avancement sur le schematic bms
    [bms.kicad_sch, drv.kicad_sch, imu.kicad_sch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]
2026-02-13 schematic bms( in progress)
    [bms.kicad_sch]
2026-02-19 tente un push
    [bms.kicad_sch, drv.kicad_sch, imu.kicad_sch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]
2026-02-19 Description de mes changements
    [tof.kicad_sch]
2026-02-19 update bms
    [bms.kicad_sch]
2026-02-19 DRV fini
    [bms.kicad_sch, drv.kicad_sch, tof.kicad_sch]
2026-02-19 fin bms schematic bms
    [bms.kicad_sch, drv.kicad_sch, pcb_pcBOT.kicad_sch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]
2026-02-19 manual merge
    [bms.kicad_sch]
2026-02-19 Schema du stm32
    [stm32. .kicad_sch]
2026-02-19 stm32 (in progress)
    [stm32.kicad_sch]
2026-02-19 small adjustments
    [stm32.kicad_sch]
2026-02-22 avancement des schematics
    [bms.kicad_sch, drv.kicad_sch, imu.kicad_sch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]
2026-02-22 ajout du module nrf + petites corrections
    [bms.kicad_sch, drv.kicad_sch, nrf.kicad_sch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]
2026-03-04 Mise à jour du schéma TOF
    [tof.kicad_sch]
2026-03-06 complement tof et connections, mise a jour du firmware
    [bms.kicad_sch, nrf.kicad_sch, pcb_pcBOT.kicad_sch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]
2026-03-09 corrections d'erreurs et liasons bus i2c et spi
    [bms.kicad_sch, pcb_pcBOT.kicad_sch, stm32.kicad_sch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]
2026-03-10 Ajout empreintes (incomplet) + test erc correct
    [bms.kicad_sch, drv.kicad_sch, imu.kicad_sch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]
2026-03-12 Revert "Ajout empreintes (incomplet) + test erc correct"
    This reverts commit 267ed5519d67c336b99c9c80b0ac2067182b82a3.
    [bms.kicad_sch, drv.kicad_sch, imu.kicad_sch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]
2026-03-12 fix pitié
    [drv.kicad_sch]
2026-03-12 fix final
    [bms.kicad_sch, imu.kicad_sch, nrf.kicad_sch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]
2026-03-12 fin de schematique
    [bms.kicad_sch, pcb_pcBOT.kicad_sch, stm32.kicad_sch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]
2026-03-12 schematique terminé + probleme empreinte réglé + début routage
    [bms.kicad_sch, imu.kicad_sch, pcb_pcBOT.kicad_pcb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]
2026-03-16 début routage premier jet
    [pcb_pcBOT.kicad_pcb]
2026-03-19 routage wip
    [pcb_pcBOT.kicad_pcb]
2026-03-19 rouatage + firmware wip
    [bms.kicad_sch, drv.kicad_sch, imu.kicad_sch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]
2026-03-24 routage wip encore
    [pcb_pcBOT.kicad_pcb, pcb_pcBOT.kicad_sch, stm32.kicad_sch]
2026-03-26 fin du routage
    [pcb_pcBOT-B_Cu.gbr, pcb_pcBOT-B_Mask.gbr, pcb_pcBOT-B_Silkscreen.gbr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]
2026-03-26 pcb v1 fini fichier envoyé à jlc
    [pcb_pcBOT-B_Cu.gbr, pcb_pcBOT-B_Mask.gbr, pcb_pcBOT-B_Silkscreen.gbr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]
2026-04-01 code genérer du ioc du stm du pcb
2026-04-01 tof codes
    [pcb_pcBOT-B_Cu.gbr, pcb_pcBOT-B_Mask.gbr, pcb_pcBOT-B_Silkscreen.gbr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]
2026-04-01 Codes IMU
2026-04-01 fix errur pin imu_int
    [pcbot.ioc]
2026-04-09 code driver
2026-04-09 ajout du code de Tof_Read

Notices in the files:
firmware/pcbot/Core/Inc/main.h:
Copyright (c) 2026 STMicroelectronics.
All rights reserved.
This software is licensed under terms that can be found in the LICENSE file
